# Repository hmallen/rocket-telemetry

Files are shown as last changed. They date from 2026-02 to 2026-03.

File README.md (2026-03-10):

# rocket-telemetry

High-rate flight data logger / telemetry firmware for a **Teensy 4.1** (Arduino framework via PlatformIO).

The firmware samples sensors, timestamps data with `micros()`, optionally anchors time to GNSS PPS, buffers records through a fast in-RAM ring (and optional PSRAM “spool”), and can write framed binary blocks to SD (Teensy 4.1 SDIO). A LoRa downlink module exists (enabled by default) and includes **FCC Part 97** guardrails.

## Status / defaults

`src/cfg.h` controls feature toggles. Current defaults in this repo:

- **SD logging**: enabled (`ENABLE_SD_LOGGER 1`)
- **PSRAM spool**: enabled (`ENABLE_PSRAM_SPOOL 1`)
- **GNSS**: enabled (`ENABLE_GNSS 1`) (raw UBX byte logging; configuration is a stub)
- **Sensors**: enabled (`ENABLE_SENSORS 1`)
- **LoRa**: enabled (`ENABLE_LORA 1`, `LORA_CONTROL_OPERATOR_OK 1`)

## Hardware

### Target MCU

- **Teensy 4.1**

### Sensors / peripherals (as implemented)

- **Barometer**: BMP3XX (configured via SPI) and BMP180 (I2C) as `baro2`
- **Gyro**: Adafruit L3GD20 (I2C)
- **Accelerometer**: Adafruit LSM303 (I2C)
- **GNSS**: two UARTs (`Serial1` primary, `Serial3` backup) + PPS input
- **SD**: Teensy 4.1 on-board SDIO (when enabled)
- **LoRa**: SX1276 via RadioLib (when enabled)

### Pin / bus configuration

All pins and bus settings are defined in `src/cfg.h`:

- **GNSS**
  - `GNSS_SERIAL_PRIMARY`: `Serial1`
  - `GNSS_SERIAL_BACKUP`: `Serial3`
  - `GNSS_PPS_PIN`: `2`
  - `GNSS_BAUD`: `115200`
- **Buzzer**: `BUZZER_PIN = 28` (short beep every ~2 seconds)
- **I2C**: `Wire`, `I2C_HZ = 400,000`
- **BMP3XX SPI**
  - `BMP_SPI_BUS = SPI`
  - `BMP_CS = 38`
- **LoRa (SX127x)**
  - `LORA_CS = 10`, `LORA_DIO0 = 9`, `LORA_RST = 8`

## Building / flashing

This is a PlatformIO project.

- **Environments**
  - `teensy41`
  - `teensy41_debug` (adds `-D DEBUG_MODE=1`)

Typical workflow (PlatformIO CLI):

```sh
pio run -e teensy41
pio run -e teensy41 -t upload
pio device monitor -b 115200
```

Serial monitor speed is `115200` (see `platformio.ini`).

## Runtime behavior (high level)

`src/main.cpp` drives the system:

- **Timebase**
  - `micros()` is the primary timestamp.
  - A PPS interrupt latches `t_us_at_pps`; a `REC_TIME_ANCHOR` record is emitted on each PPS edge.
- **GNSS**
  - Raw bytes from UART(s) are packed into `REC_GNSS_CHUNK` records.
  - Basic failover selects the “fresh” receiver based on a timeout (`GNSS_FAILOVER_TIMEOUT_US`).
  - Module configuration is currently a stub in `GnssUbx::configure()`.
- **Sensors**
  - Baro is sampled at `BARO_HZ`.
  - IMU sampling is scheduled at `IMU_HZ`.
- **Buffering**
  - Records are written into an internal `ByteRing` (DMA memory).
  - If enabled, the ring is drained into a PSRAM spool (`PsramSpool`) to absorb bursts.
- **SD block writing**
  - Data is drained into a `BlockBuilder` and written in 32 KiB blocks (when `ENABLE_SD_LOGGER` is enabled).

## Data format

### Record stream

Records are packed structs defined in `src/records.h`, each beginning with:

- `RecHdr { type, ver, len }`

Record types currently used:

- `REC_IMU_FAST` (accel/gyro)
- `REC_BARO`
- `REC_BARO2` (BMP180)
- `REC_GNSS_CHUNK` (raw bytes)
- `REC_TIME_ANCHOR` (PPS-to-GNSS time anchor)
- `REC_EVENT` (markers)
- `REC_STATS` (drop counters, voltages, SD write error counter)

### SD block framing

When SD logging is enabled, data is written as a sequence of blocks:

- `BlockHdr` (see `records.h`)
  - `magic`: `0x424D4C54` (`'TLMB'`)
  - `ver`: `1`
  - `seq`: monotonic block number
  - `t_start_us`: `micros()` at block start
  - `payload_len`: bytes following the header
  - `crc32`: CRC32 of payload
- `payload`: concatenated record bytes

Log files are named `LOG00000.BIN`, `LOG00001.BIN`, ... and are preallocated (see `PREALLOC_BYTES`).

## LoRa telemetry

The LoRa downlink code (`src/lora_link.*`) is intended for **FCC Part 97** amateur telemetry and includes multiple safeguards:

- Transmit is blocked unless you explicitly set `LORA_CONTROL_OPERATOR_OK 1`.
- Transmit is disabled at boot by default (`LORA_TX_ENABLE_AT_BOOT 0`).
- Telemetry payload uses a **custom binary format** and includes the callsign as an identifier byte sequence.

If you enable LoRa, you must also set a real `LORA_CALLSIGN` and ensure you are operating legally and under appropriate supervision.

## Tuning / configuration

Edit `src/cfg.h` for:

- Sample rates (`IMU_HZ`, `BARO_HZ`, `GNSS_HZ`, `LORA_HZ`)
- Buffer sizes (`RING_BYTES`, `SPOOL_BYTES`)
- SD write/sync parameters (`LOG_BLOCK_BYTES`, `SD_SYNC_MS`, `PREALLOC_BYTES`)
- Enabling/disabling features (the `ENABLE_*` macros)

## Receiver Tools

The project includes several ground-side companion tools located in the `receiver/` directory:

- **ESP32 Companion** (`receiver/esp32-companion`): An ESP32-based application using the Arduino framework and LVGL to display live telemetry data received over LoRa.
- **Pi Ground Station** (`receiver/pi`): A Python-based ground station server designed to run on a Raspberry Pi, providing a web interface, logging, and mapping capabilities.
- **Pico Emulator** (`receiver/pico`): A LoRa flight emulator for the Raspberry Pi Pico to generate simulated telemetry data for testing ground station setups.

## License

See `LICENSE`.

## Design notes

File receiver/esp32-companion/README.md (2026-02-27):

# ESP32 Companion Display (LVGL / CrowPanel 3.5)

This firmware targets the **CrowPanel 3.5" ESP32 HMI (480x320 landscape)** as a
ground-station telemetry display.

## What this now includes

- Full LVGL-based UI (rebuilt from scratch)
- UART-first companion transport to Pi ground station
- Optional Wi-Fi API/SSE transport fallback
- Optional Arduino OTA updates over Wi-Fi
- Optional SD-backed WAV playback for key flight events (armed-waiting, liftoff, apogee, drogue, main, landing)
- Telemetry dashboard:
  - Link status, RSSI, SNR, packet age
  - Flight phase, altitude AGL, vertical speed
  - Packet count, callsign
  - `TX_VBAT` (rocket telemetry battery)
  - `BAT_ADC` (local display board battery ADC)
- Collapsible action panel:
  - `BUZZER 1s`
  - `BUZZER 5s`
  - `SD START`
  - `SD STOP`
  - `TX ENABLE`
  - `TX DISABLE`
- Collapsible settings menu with touch calibration flow
- Touch calibration persistence in NVS (`Preferences`)

## Build + flash

```bash
pio run -e esp32dev
pio run -e esp32dev -t upload
pio device monitor -b 115200
```

OTA upload (after first USB flash and with OTA enabled in config):

```bash
pio run -e esp32dev-ota -t upload
```

## Configuration

1. Copy config template:

```bash
cp include/config.h.example include/config.h
```

2. Edit `include/config.h`:

- `COMPANION_LINK_UART` (`1` recommended for ground station)
- UART pins/baud for your board revision
- Wi-Fi + host settings if using API/SSE mode
- auth token if `/api/companion/cmd` is protected
- optional SD bootstrap (`COMPANION_SD_ENABLE`, `COMPANION_SD_CS_PIN`, `COMPANION_SD_SPI_FREQ`, `COMPANION_SD_SCK_PIN`, `COMPANION_SD_MISO_PIN`, `COMPANION_SD_MOSI_PIN`, `COMPANION_SD_SOUND_DIR`) for future sound assets
- optional event audio output (`COMPANION_AUDIO_ENABLE`, `COMPANION_AUDIO_SPK_PIN`, `COMPANION_AUDIO_PWM_*`) and per-event WAV file paths (`COMPANION_SOUND_FILE_*`)
- OTA settings (`OTA_ENABLE`, `OTA_HOSTNAME`, `OTA_PORT`, `OTA_PASSWORD`) if using OTA updates

When `OTA_ENABLE=1`, firmware keeps Wi-Fi active even in UART transport mode so OTA
updates remain available.

## Sound asset checklist (SD card)

Place WAV files under the SD sound directory (default: `/sounds`, configured by
`COMPANION_SD_SOUND_DIR`).

Primary event cues (via `COMPANION_SOUND_FILE_*` macros):

- `power_on.wav`
- `armed.wav`
- `calibrating.wav`
- `sensors_ready.wav`
- `waiting_for_location_fix.wav`
- `location_fix_acquired.wav`
- `launch_detect_mode.wav`
- `launch_detected.wav`
- `apogee.wav`
- `drogue_deployed.wav`
- `main_deployed.wav`
- `landing_detected.wav`
- `audio_test.wav` (used by **Play Test Sound**)

Spoken apogee altitude callout after landing requires numeric/unit clips:

- Number clips as `/sounds/<N>.wav` for:
  - 1..20
  - multiples of 10 below 100
  - multiples of 100 below 1000
  - multiples of 1000 up to 10000
- Unit clip: `meters.wav`

## CrowPanel pin notes

`platformio.ini` is configured for CrowPanel 3.5 with ILI9488 + XPT2046 defaults.

- Default profile uses: `TFT_MISO=12`, `TOUCH_CS=33`
- Elecrow v2.2 boards may require: `TFT_MISO=33`, `TOUCH_CS=12`

If your panel revision differs, override build flags in `platformio.ini`.

## Touch calibration

Use **Settings -> Calibrate Touch** from the LVGL action panel.

The calibration flow captures all four corners and stores bounds/swap config in
NVS so they persist across reboots.

## UART protocol

See `UART_PROTOCOL.md` for frame details and command IDs used between Pi and ESP32.

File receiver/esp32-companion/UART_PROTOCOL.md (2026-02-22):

# Companion UART Protocol (Pi Ground Station ↔ ESP32)

This defines the direct wired fallback/primary transport for the companion display
when the **ground station host is the Raspberry Pi**.

## Wiring

- Pi TX -> ESP32 RX (UART)
- Pi RX <- ESP32 TX (UART)
- GND -> GND
- 3.3V logic levels only on UART signal lines

Pi note:
- Use the Pi UART on GPIO14/15 (`/dev/serial0` preferred).
- Disable Linux serial console on that UART if needed, so your app has exclusive access.

ESP32 board note (LCDWiki E32R32P/E32N32P):
- The exposed UART header is tied to ESP32 UART0 (`RXD0=IO3`, `TXD0=IO1`) per LCDWiki docs.
- GPIO numbers are ESP32 GPIO IDs (not Raspberry Pi BCM numbering).

## Frame format

```text
SOF1  SOF2  VER  TYPE  SEQ(2)  LEN(2)  PAYLOAD(LEN)  CRC16(2)
0xA5  0x5A  0x01
```

CRC16 is CCITT over: `VER..PAYLOAD`.

## Message types

- `0x01` `MSG_TELEM_SNAPSHOT` (Pi -> ESP32)
- `0x02` `MSG_ALERT_EVENT` (Pi -> ESP32)
- `0x03` `MSG_HEARTBEAT` (both)
- `0x10` `MSG_CMD` (ESP32 -> Pi)
- `0x11` `MSG_CMD_ACK` (Pi -> ESP32)

## Transport selection

In `include/config.h`:

```cpp
#define COMPANION_LINK_UART 1
#define UART_BAUD 115200
#define UART_RX_PIN 3
#define UART_TX_PIN 1
```

On LCDWiki E32R32P/E32N32P, these map to UART0 (`RXD0=IO3`, `TXD0=IO1`) on the
exposed UART header.

Set `COMPANION_LINK_UART 0` to use Wi-Fi API/SSE instead.

## ESP32 implementation

- Parser/encoder: `src/serial/uart_proto.*`
- UART state bridge: `src/serial/uart_link.*`
- Controller auto-switches between UART and Wi-Fi using `COMPANION_LINK_UART`.

## Host-side implementation guidance (Pi)

Run a small UART bridge process on the Pi that:

1. Encodes telemetry into `MSG_TELEM_SNAPSHOT` frames at ~10 Hz
2. Parses incoming `MSG_CMD` from ESP32
3. Executes command actions in ground-station code (`buzzer`, `sd_start`, `sd_stop`)
4. Replies with `MSG_CMD_ACK`

This repository now treats UART companion mode as **Pi ground station ↔ ESP32**.

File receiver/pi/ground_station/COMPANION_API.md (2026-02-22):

# Companion Display API (ESP32 Touchscreen)

This API is intended for a Pi-companion touchscreen display (ESP32) and is separate from the browser UI API.

## Endpoints

### `GET /api/companion/state`
Returns a lightweight telemetry snapshot suitable for ESP32 rendering.

Response:

```json
{
  "state": {
    "ts": 1771290000.123,
    "seq": 123,
    "link": {
      "connected": true,
      "rssi": -91,
      "snr": 7.25,
      "crc_ok": true,
      "last_packet_age_ms": 84
    },
    "flight": {
      "phase": "coast",
      "packet_count": 2812,
      "callsign": "N0CALL"
    },
    "gps": { "lat_deg": 32.99, "lon_deg": -96.75, "alt_m": 512.3, "svs_used": 10, "svs_total": 18 },
    "alt": { "press_kpa": 98.7, "temp_c": 24.3 },
    "imu": { "ax_g": 0.02, "ay_g": -0.01, "az_g": 1.01, "gx_dps": 0.6, "gy_dps": -0.2, "gz_dps": 0.3 },
    "attitude": { "roll": 2.1, "pitch": -0.8, "yaw": 178.3, "filter": "madgwick" },
    "battery": { "vbat_v": 3.96, "bat_state_label": "OK" },
    "recovery": {
      "enabled": true,
      "phase": "coast",
      "altitude_agl_m": 402.1,
      "max_altitude_agl_m": 410.8,
      "vertical_speed_mps": 92.4,
      "drogue": { "deployed": false },
      "main": { "deployed": false }
    },
    "alerts": []
  }
}
```

### `GET /api/companion/events` (SSE)
SSE stream for live updates.

- `event: telemetry` for normal updates
- `event: hb` for heartbeat keepalive (1s cadence)

Example telemetry payload:

```json
{
  "event": "telemetry",
  "state": { "seq": 124, "link": { "rssi": -93 } }
}
```

### `POST /api/companion/cmd`
Sends a command through the same command path used by `/api/command`.

Auth required with either:
- `Authorization: Bearer <GS_AUTH_TOKEN>`
- `X-Auth-Token: <GS_AUTH_TOKEN>`

Request body examples:

```json
{"action": "sd_start"}
```

```json
{"action": "sd_stop"}
```

```json
{"action": "buzzer", "duration_s": 5}
```

## Notes

- The companion API is intentionally small and stable for microcontroller clients.
- `alerts` includes link staleness and low battery warnings for direct UI signaling.
- Link state is derived from telemetry timestamp freshness.

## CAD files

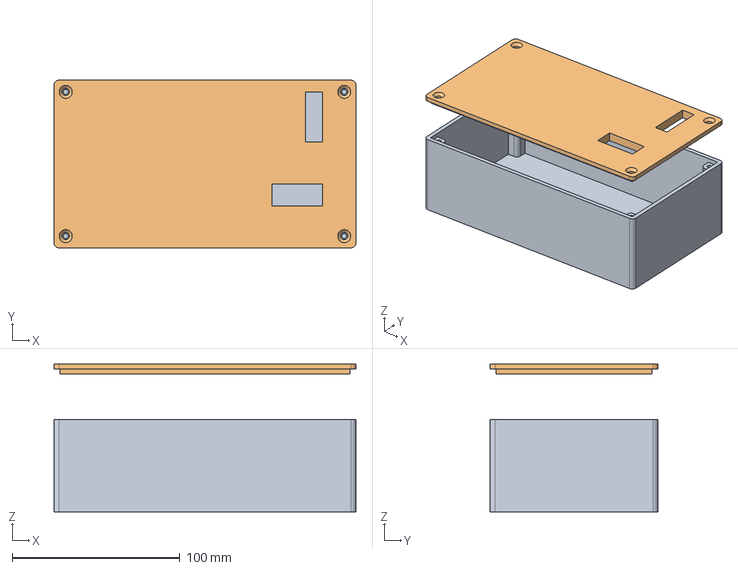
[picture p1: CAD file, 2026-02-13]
receiver/pi/enclosure/receiver_enclosure.FCStd
180.0 x 100.0 x 88.0 mm

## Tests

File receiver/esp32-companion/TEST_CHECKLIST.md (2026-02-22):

# ESP32 Companion Display Test Checklist

Use this checklist before field deployment.

## Bench Test (Required)

- [ ] Build firmware successfully (`pio run`)
- [ ] Flash device (`pio run -t upload`)
- [ ] Device boots with no crash loop (`pio device monitor`)
- [ ] Stale indicator appears after >3s without telemetry
- [ ] `BUZZ 1s` touch command works
- [ ] `BUZZ 5s` touch command works
- [ ] `SD TOGGLE` starts/stops logging as expected
- [ ] Command failures show error feedback on screen
- [ ] Touch calibration mode opens (top-left) and exits (top-right)
- [ ] Mapped touch coordinates align with button hitboxes

## Bench Test: Wi-Fi Mode (`COMPANION_LINK_UART=0`)

- [ ] Serial monitor shows Wi-Fi connect and no reconnect storm
- [ ] `GET /api/companion/state` returns valid JSON from Pi
- [ ] SSE stream connects (`/api/companion/events`) and updates continuously
- [ ] Link status changes correctly when Pi service is stopped/restarted

## Bench Test: UART Mode (`COMPANION_LINK_UART=1`)

- [ ] Wiring verified: Pi TX -> ESP32 RX, Pi RX <- ESP32 TX, GND common
- [ ] Logic level verified: UART signals are 3.3V (no 5V on RX/TX)
- [ ] UART config matches both sides (baud + pins)
- [ ] ESP32 receives telemetry over UART and updates phase/altitude/packet count
- [ ] Pulling one UART wire causes stale/link-down indication within ~3s
- [ ] Reconnecting UART recovers without reboot
- [ ] UART command path works end-to-end (BUZZ/SD toggle + ACK feedback)
- [ ] No framing instability under load (no persistent garbage/lock-up)

## Security & Network

- [ ] `GS_AUTH_TOKEN` is set on ESP32 when command auth is enabled on Pi
- [ ] `/api/companion/cmd` returns 401 without token (when auth enabled)
- [ ] Pi bind/access mode matches expected launch network policy

## UART Robustness (Recommended)

- [ ] 30+ minute run with continuous UART telemetry has no parser lockup
- [ ] Power cycle ESP32 while Pi ground station runs: link recovers automatically
- [ ] Restart/power cycle Pi ground station while ESP32 runs: stale alarm then recovery
- [ ] Cable wiggle test does not trigger false commands
- [ ] Command retry/timeout behavior is acceptable for field use

## Field Simulation (Recommended)

- [ ] Ground station runs for 30+ minutes without UI freeze
- [ ] Reconnect behavior works after Wi-Fi disruption/rejoin
- [ ] Alert strip shows phase transitions and link events
- [ ] Display remains readable in expected daylight conditions
- [ ] No accidental command triggers from noisy touch events

## Pre-Launch

- [ ] Confirm final touch calibration constants in `include/config.h`
- [ ] Confirm selected transport mode (`COMPANION_LINK_UART` 0 or 1)
- [ ] If Wi-Fi mode: confirm correct ground station host/IP and port
- [ ] If UART mode: confirm final UART pins/baud and cable strain relief
- [ ] Confirm buzzer + SD command behavior with live radio link
- [ ] Keep fallback control path available (laptop/web UI)

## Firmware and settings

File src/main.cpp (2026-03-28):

#include <Arduino.h>

#include "cfg.h"
#include "records.h"
#include "byte_ring.h"
#include "psram_spool.h"
#include "block_builder.h"
#include "crc32.h"
#include "sd_logger.h"
#include "timebase.h"
#include "gnss_ubx.h"
#include "sensors.h"
#include "lora_link.h"

// Internal fast ring
DMAMEM static uint8_t ring_mem[RING_BYTES];
static ByteRing ring;

// PSRAM spool
#if ENABLE_PSRAM_SPOOL
EXTMEM static uint8_t spool_mem[SPOOL_BYTES];
static PsramSpool spool;
#endif

static BlockBuilder block;
static SdLogger sdlog;
static uint32_t block_seq = 0;
static bool sd_logging_enabled = false;
constexpr uint32_t SD_ROTATE_DRAIN_MAX_MS = 3000;

static inline bool build_and_write_block_from_source(uint32_t now_ms, bool force_write = false);
static inline void pump_ring_to_spool();
static void sd_logging_flush_pending(uint32_t now_ms, uint32_t max_drain_ms);
static inline void ring_write_sd_log_open_event(int16_t reason);
static inline void ring_write_sd_log_close_event(int16_t reason);

#if ENABLE_SD_DUMP
static const char* sd_dump_record_name(uint8_t type) {
  switch (type) {
    case REC_IMU_FAST: return "REC_IMU_FAST";
    case REC_BARO: return "REC_BARO";
    case REC_GNSS_CHUNK: return "REC_GNSS_CHUNK";
    case REC_TIME_ANCHOR: return "REC_TIME_ANCHOR";
    case REC_EVENT: return "REC_EVENT";
    case REC_STATS: return "REC_STATS";
    case REC_BARO2: return "REC_BARO2";
    default: return "REC_UNKNOWN";
  }
}

static void sd_dump_print_ascii(const uint8_t* data, uint16_t n, uint16_t preview) {
  Serial.print("    ascii: ");
  for (uint16_t i = 0; i < preview; ++i) {
    char c = (data[i] >= 32 && data[i] <= 126) ? (char)data[i] : '.';
    Serial.write(c);
  }
  if (n > preview) {
    Serial.print(" ...");
  }
  Serial.println();
}

static void sd_dump_print_hex(const uint8_t* data, uint16_t n, uint16_t preview) {
  Serial.print("    hex:   ");
  for (uint16_t i = 0; i < preview; ++i) {
    if (i && (i % 16 == 0)) {
      Serial.print("\n          ");
    }
    if (data[i] < 0x10) Serial.print('0');
    Serial.print(data[i], HEX);
    Serial.print(' ');
  }
  if (n > preview) {
    Serial.print("... (");
    Serial.print(n);
    Serial.println(" bytes)");
  } else {
    Serial.println();
  }
}

static void sd_dump_print_record(uint32_t idx,
                                 uint8_t type,
                                 uint8_t ver,
                                 uint16_t len,
                                 const uint8_t* payload,
                                 uint16_t payload_len) {
  const char* name = sd_dump_record_name(type);
  Serial.printf("  [%lu] %s ver=%u len=%u\n",
                (unsigned long)idx, name, (unsigned)ver, (unsigned)len);
  const uint16_t preview = min(payload_len, (uint16_t)64);

  if (type == REC_IMU_FAST && payload_len >= (sizeof(RecImuFast) - sizeof(RecHdr))) {
    RecImuFast r{};
    memcpy(&r.t_us, payload, sizeof(RecImuFast) - sizeof(RecHdr));
    Serial.printf("    t_us=%lu ax=%d ay=%d az=%d gx=%d gy=%d gz=%d temp=%d status=0x%04x\n",
                  (unsigned long)r.t_us, (int)r.ax, (int)r.ay, (int)r.az,
                  (int)r.gx, (int)r.gy, (int)r.gz, (int)r.temp, (unsigned)r.status);
    return;
  }
  if ((type == REC_BARO || type == REC_BARO2) && payload_len >= (sizeof(RecBaro) - sizeof(RecHdr))) {
    RecBaro r{};
    memcpy(&r.t_us, payload, sizeof(RecBaro) - sizeof(RecHdr));
    Serial.printf("    t_us=%lu press_pa_x10=%ld temp_c_x100=%d status=0x%04x\n",
                  (unsigned long)r.t_us, (long)r.press_pa_x10, (int)r.temp_c_x100,
                  (unsigned)r.status);
    return;
  }
  if (type == REC_GNSS_CHUNK && payload_len >= 6) {
    uint32_t t_us = 0;
    uint16_t n = 0;
    memcpy(&t_us, payload, sizeof(t_us));
    memcpy(&n, payload + sizeof(t_us), sizeof(n));
    uint16_t avail = payload_len > 6 ? (payload_len - 6) : 0;
    uint16_t n_use = min(n, avail);
    Serial.printf("    t_us=%lu n=%u\n", (unsigned long)t_us, (unsigned)n);
    if (n_use) {
      const uint8_t* data = payload + 6;
      sd_dump_print_ascii(data, n_use, min(n_use, preview));
      sd_dump_print_hex(data, n_use, min(n_use, preview));
    }
    return;
  }
  if (type == REC_TIME_ANCHOR && payload_len >= (sizeof(RecTimeAnchor) - sizeof(RecHdr))) {
    RecTimeAnchor r{};
    memcpy(&r.t_us_at_pps, payload, sizeof(RecTimeAnchor) - sizeof(RecHdr));
    Serial.printf("    t_us_at_pps=%lu gps_week=%u tow_ms=%lu fix_ok=%u\n",
                  (unsigned long)r.t_us_at_pps, (unsigned)r.gps_week,
                  (unsigned long)r.tow_ms, (unsigned)r.fix_ok);
    return;
  }
  if (type == REC_EVENT && payload_len >= (sizeof(RecEvent) - sizeof(RecHdr))) {
    RecEvent r{};
    memcpy(&r.t_us, payload, sizeof(RecEvent) - sizeof(RecHdr));
    if (record_event_is_lora_cmd_rx(r.event_id)) {
      const uint8_t cmd = record_event_lora_cmd_rx_cmd(r.event_id);
      const char* cmd_name = record_lora_cmd_name(cmd);
      Serial.printf("    t_us=%lu event=gs_cmd_rx cmd=0x%02X (%s) arg=%d\n",
                    (unsigned long)r.t_us,
                    (unsigned)cmd,
                    cmd_name != nullptr ? cmd_name : "unknown",
                    (int)r.value);
    } else if (record_event_is_sd_log_open(r.event_id)) {
      const char* reason = record_sd_log_open_reason_name(r.value);
      Serial.printf("    t_us=%lu event=sd_log_open reason=%s(%d)\n",
                    (unsigned long)r.t_us,
                    reason != nullptr ? reason : "unknown",
                    (int)r.value);
    } else if (record_event_is_sd_log_close(r.event_id)) {
      const char* reason = record_sd_log_close_reason_name(r.value);
      Serial.printf("    t_us=%lu event=sd_log_close reason=%s(%d)\n",
                    (unsigned long)r.t_us,
                    reason != nullptr ? reason : "unknown",
                    (int)r.value);
    } else {
      Serial.printf("    t_us=%lu event_id=%u value=%d\n",
                    (unsigned long)r.t_us, (unsigned)r.event_id, (int)r.value);
    }
    return;
  }
  if (type == REC_STATS && payload_len >= (sizeof(RecStats) - sizeof(RecHdr))) {
    RecStats r{};
    memcpy(&r.t_us, payload, sizeof(RecStats) - sizeof(RecHdr));
    Serial.printf("    t_us=%lu ring_drops=%lu spool_drops=%lu sd_write_errs=%lu vbat_mv=%u bat_state=%u\n",
                  (unsigned long)r.t_us, (unsigned long)r.ring_drops,
                  (unsigned long)r.spool_drops, (unsigned long)r.sd_write_errs,
                  (unsigned)r.vbat_mv, (unsigned)r.bat_state);
    return;
  }

  if (payload_len) {
    sd_dump_print_hex(payload, payload_len, preview);
  }
}

static bool sd_dump_skip_bytes(FsFile& file, uint32_t n, uint32_t* crc) {
  uint8_t scratch[64];
  while (n) {
    uint32_t chunk = min(n, (uint32_t)sizeof(scratch));
    int32_t r = file.read(scratch, chunk);
    if (r <= 0) return false;
    if (crc) {
      *crc = crc32_update(*crc, scratch, (size_t)r);
    }
    n -= (uint32_t)r;
  }
  return true;
}

static void sd_dump_log() {
  Serial.println("\nsd: dump requested");
#if !ENABLE_SD_LOGGER
  Serial.println("sd: logging disabled");
  return;
#endif
  sdlog.force_sync();
  const char* log_name = sdlog.log_name();
  if (!log_name) {
    Serial.println("sd: no log file name");
    return;
  }

  FsFile file = sdlog.open_log_read();
  if (!file) {
    Serial.println("sd: open log for read failed");
    return;
  }

  if (!file.seekSet(0)) {
    Serial.println("sd: seek failed");
    file.close();
    return;
  }

  Serial.print("sd: dumping ");
  Serial.println(log_name);

  uint32_t block_idx = 0;
  while (true) {
    BlockHdr hdr{};
    int32_t r = file.read((uint8_t*)&hdr, sizeof(hdr));
    if (r == 0) break;
    if (r < (int32_t)sizeof(hdr)) {
      Serial.println("sd: truncated block header");
      break;
    }
    if (hdr.hdr_len < sizeof(hdr)) {
      Serial.println("sd: invalid block header length");
      break;
    }
    if (hdr.hdr_len > sizeof(hdr)) {
      if (!sd_dump_skip_bytes(file, hdr.hdr_len - sizeof(hdr), nullptr)) {
        Serial.println("sd: truncated block header padding");
        break;
      }
    }

    if (hdr.magic != BLOCK_MAGIC) {
      if (hdr.magic == 0) {
        Serial.println("sd: reached preallocated empty region");
      } else {
        Serial.printf("sd: invalid block magic 0x%08lx\n", (unsigned long)hdr.magic);
      }
      break;
    }

    Serial.printf("BLOCK seq=%lu t_start_us=%lu payload_len=%lu\n",
                  (unsigned long)hdr.seq,
                  (unsigned long)hdr.t_start_us,
                  (unsigned long)hdr.payload_len);

    uint32_t remaining = hdr.payload_len;
    uint32_t crc = 0u;
    uint32_t rec_idx = 0;

    while (remaining >= sizeof(RecHdr)) {
      uint8_t rec_hdr[sizeof(RecHdr)];
      int32_t rh = file.read(rec_hdr, sizeof(rec_hdr));
      if (rh < (int32_t)sizeof(rec_hdr)) {
        Serial.println("sd: truncated record header");
        remaining = 0;
        break;
      }
      remaining -= sizeof(rec_hdr);
      crc = crc32_update(crc, rec_hdr, sizeof(rec_hdr));

      const uint8_t rec_type = rec_hdr[0];
      const uint8_t rec_ver = rec_hdr[1];
      const uint16_t rec_len = (uint16_t)rec_hdr[2] | ((uint16_t)rec_hdr[3] << 8);
      if (rec_len < sizeof(RecHdr) || rec_len - sizeof(RecHdr) > remaining) {
        Serial.println("sd: invalid record length");
        if (!sd_dump_skip_bytes(file, remaining, &crc)) {
          remaining = 0;
        }
        break;
      }

      const uint16_t payload_len = rec_len - sizeof(RecHdr);
      uint8_t rec_buf[GNSS_CHUNK_MAX + 16];
      uint16_t to_read = payload_len;
      if (to_read > sizeof(rec_buf)) {
        to_read = sizeof(rec_buf);
      }
      if (to_read) {
        int32_t rp = file.read(rec_buf, to_read);
        if (rp < (int32_t)to_read) {
          Serial.println("sd: truncated record payload");
          remaining = 0;
          break;
        }
        crc = crc32_update(crc, rec_buf, to_read);
      }

      if (payload_len > to_read) {
        uint32_t leftover = payload_len - to_read;
        if (!sd_dump_skip_bytes(file, leftover, &crc)) {
          Serial.println("sd: truncated record payload");
          remaining = 0;
          break;
        }
      }

      remaining -= payload_len;
      sd_dump_print_record(rec_idx, rec_type, rec_ver, rec_len, rec_buf, min(payload_len, to_read));
      rec_idx++;
    }

    if (remaining) {
      sd_dump_skip_bytes(file, remaining, &crc);
    }

    const bool crc_ok = (crc == hdr.crc32);
    Serial.printf("BLOCK CRC32 %s (0x%08lx)\n", crc_ok ? "OK" : "BAD", (unsigned long)crc);
    block_idx++;
  }

  file.close();
  Serial.println("sd: dump complete");
}

static void sd_clear_logs() {
  Serial.println("\nsd: clear requested");
#if !ENABLE_SD_LOGGER
  Serial.println("sd: logging disabled");
  return;
#endif
  const bool restart_logging = sd_logging_enabled;
  if (sd_logging_enabled) {
    ring_write_sd_log_close_event(REC_EVENT_VALUE_SD_LOG_CLOSE_CLEAR);
    sd_logging_flush_pending(millis(), SD_ROTATE_DRAIN_MAX_MS);
    sdlog.force_sync();
    if (!sdlog.close_log()) {
      Serial.println("sd: close failed before clear");
    }
    sd_logging_enabled = false;
  }
  if (!sdlog.clear_logs()) {
    Serial.println("sd: clear failed");
    return;
  }

  block_seq = 0;
  block.reset(block_seq, micros());
  ring.init(ring_mem, RING_BYTES);
#if ENABLE_PSRAM_SPOOL
  spool.init(spool_mem, SPOOL_BYTES);
#endif
  sd_logging_enabled = false;

  if (restart_logging) {
    if (!sdlog.open_new_log(PREALLOC_BYTES)) {
      Serial.println("sd: open new log failed");
      return;
    }

    sd_logging_enabled = true;
    ring_write_sd_log_open_event(REC_EVENT_VALUE_SD_LOG_OPEN_RESTART);
    sd_logging_flush_pending(millis(), SD_ROTATE_DRAIN_MAX_MS);
    const char* log_name = sdlog.log_name();
    if (log_name) {
      Serial.print("sd: new log ");
      Serial.println(log_name);
    } else {
      Serial.println("sd: new log started");
    }
  }
}

static void sd_rotate_log() {
  Serial.println("\nsd: rotate requested");
#if !ENABLE_SD_LOGGER
  Serial.println("sd: logging disabled");
  return;
#endif
  char old_name[32];
  old_name[0] = '\0';
  const char* log_name = sdlog.log_name();
  if (log_name) {
    snprintf(old_name, sizeof(old_name), "%s", log_name);
  }

  ring_write_sd_log_close_event(REC_EVENT_VALUE_SD_LOG_CLOSE_ROTATE);
  sd_logging_flush_pending(millis(), SD_ROTATE_DRAIN_MAX_MS);

  if (!sdlog.close_log()) {
    Serial.println("sd: close failed");
  }
  if (!sdlog.open_new_log(PREALLOC_BYTES)) {
    Serial.println("sd: open new log failed");
    sd_logging_enabled = false;
    return;
  }

  sd_logging_enabled = true;
  ring_write_sd_log_open_event(REC_EVENT_VALUE_SD_LOG_OPEN_ROTATE);
  sd_logging_flush_pending(millis(), SD_ROTATE_DRAIN_MAX_MS);
  if (old_name[0]) {
    Serial.print("sd: closed ");
    Serial.println(old_name);
  }
  log_name = sdlog.log_name();
  if (log_name) {
    Serial.print("sd: new log ");
    Serial.println(log_name);
  }
}

static void sd_dump_print_help() {
  Serial.println("sd dump commands:");
  Serial.println("  c: clear SD logs (keeps logging off unless already on)");
  Serial.println("  d: dump SD log to serial");
  Serial.println("  n: close current log + start new log");
  Serial.println("  h/? : help");
}
#endif
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
void loop() {
  static uint32_t last_imu_us  = 0;
  static uint32_t last_baro_us = 0;
  static uint32_t last_baro2_us = 0;
  static int32_t last_press_pa_x10 = 0;
  static int16_t last_temp_c_x100 = 0;
  static uint32_t last_stats_ms = 0;
  static bool primary_3d_beeped = false;
  static ImuSample last_imu_sample{};
  static bool have_imu_sample = false;

  static float vbat_filt_v = 0.0f;
  static uint32_t vbat_last_sample_ms = 0;
  static uint32_t shed_below_start_ms = 0;
  static uint32_t cutoff_below_start_ms = 0;

#if DEBUG_MODE
  static uint32_t last_dbg_ms = 0;
  static ImuSample last_imu{};
  static uint32_t last_imu_dbg_us = 0;
#endif

  const uint32_t now_us = micros();
  const uint32_t now_ms = millis();

#if ENABLE_SD_DUMP
  while (Serial.available()) {
    const int c = Serial.read();
    if (c < 0) break;
    if (c == 'c' || c == 'C') {
      sd_clear_logs();
    } else if (c == 'd' || c == 'D') {
      sd_dump_log();
    } else if (c == 'n' || c == 'N') {
      sd_rotate_log();
    } else if (c == 'h' || c == '?') {
      sd_dump_print_help();
    }
  }
#endif

  if (vbat_last_sample_ms == 0 || (uint32_t)(now_ms - vbat_last_sample_ms) >= 50) {
    vbat_last_sample_ms = now_ms;

    uint32_t sum = 0;
    for (uint8_t i = 0; i < VBAT_AVG_SAMPLES; ++i) {
      sum += (uint32_t)analogRead(VBAT_PIN);
    }
    const float counts = (float)sum / (float)VBAT_AVG_SAMPLES;
    const float vadc = counts * (3.3f / 4095.0f);
    const float vbat = vadc * VBAT_DIVIDER_SCALE * VBAT_CAL_SCALE;

    if (vbat_filt_v == 0.0f) vbat_filt_v = vbat;
    else vbat_filt_v = vbat_filt_v + VBAT_LP_ALPHA * (vbat - vbat_filt_v);

    const float vf = vbat_filt_v;

    if (g_bat_state == BAT_OK) {
      if (vf <= VBAT_WARN_V) g_bat_state = BAT_WARN;
    } else if (g_bat_state == BAT_WARN) {
      if (vf <= VBAT_SHED_V) {
        if (shed_below_start_ms == 0) shed_below_start_ms = now_ms;
        if ((uint32_t)(now_ms - shed_below_start_ms) >= VBAT_DWELL_MS) {
          g_bat_state = BAT_SHED;
          shed_below_start_ms = 0;
        }
      } else {
        shed_below_start_ms = 0;
      }
      if (vf >= (VBAT_WARN_V + VBAT_HYST_V)) g_bat_state = BAT_OK;
    } else if (g_bat_state == BAT_SHED) {
      if (vf <= VBAT_CUTOFF_V) {
        if (cutoff_below_start_ms == 0) cutoff_below_start_ms = now_ms;
        if ((uint32_t)(now_ms - cutoff_below_start_ms) >= VBAT_DWELL_MS) {
          g_bat_state = BAT_CUTOFF;
          cutoff_below_start_ms = 0;
        }
      } else {
        cutoff_below_start_ms = 0;
      }
      if (vf >= (VBAT_SHED_V + VBAT_HYST_V)) g_bat_state = BAT_WARN;
    } else {
      if (vf >= (VBAT_CUTOFF_V + VBAT_HYST_V)) g_bat_state = BAT_SHED;
    }

    if (SENSOR_RAIL_EN_PIN != 255) {
      const bool rail_on = (g_bat_state == BAT_OK) || (g_bat_state == BAT_WARN);
      digitalWrite(SENSOR_RAIL_EN_PIN, rail_on ? HIGH : LOW);
    }

    g_vbat_mv = (uint16_t)max(0, (int)lrintf(vf * 1000.0f));
  }

  buzzer_poll(now_ms);

#if DEBUG_MODE
  if ((uint32_t)(now_ms - last_dbg_ms) >= 1000) {
    last_dbg_ms = now_ms;
    DBG_PRINTF("t=%lu ms baro_pa=%.1f temp_c=%.2f vbat=%.3f bat_state=%u ring_avail=%lu ring_drops=%lu",
               (unsigned long)now_ms,
               (double)last_press_pa_x10 / 10.0,
               (double)last_temp_c_x100 / 100.0,
               (double)g_vbat_mv / 1000.0,
               (unsigned)g_bat_state,
               (unsigned long)ring.available(), (unsigned long)ring.drops());
    if (last_imu_dbg_us != 0) {
      DBG_PRINTF(" imu_ax=%d ay=%d az=%d gx=%d gy=%d gz=%d ist=0x%04x",
                 (int)last_imu.ax, (int)last_imu.ay, (int)last_imu.az,
                 (int)last_imu.gx, (int)last_imu.gy, (int)last_imu.gz,
                 (unsigned)last_imu.status);
    } else {
      DBG_PRINT(" imu=none");
    }
#if ENABLE_PSRAM_SPOOL
    DBG_PRINTF(" spool_avail=%lu spool_drops=%lu", (unsigned long)spool.available(),
               (unsigned long)spool.drops());
#endif
#if ENABLE_GNSS
    const bool primary_fresh_dbg = gnss_primary.fresh(now_us, GNSS_FAILOVER_TIMEOUT_US);
    const bool backup_fresh_dbg  = gnss_backup.fresh(now_us, GNSS_FAILOVER_TIMEOUT_US);
    const bool primary_parsed_dbg = gnss_primary.parsed_fresh(now_us, GNSS_FAILOVER_TIMEOUT_US);
    const bool backup_parsed_dbg  = gnss_backup.parsed_fresh(now_us, GNSS_FAILOVER_TIMEOUT_US);
    const GnssTime& pt = gnss_primary.time();
    const GnssTime& bt = gnss_backup.time();

    DBG_PRINTF(" gnss_sel=%c", gnss_use_backup_as_primary ? 'B' : 'P');
    DBG_PRINTF(" gnss_p_fresh=%u parsed=%u fix_ok=%u fix=%u lat=%.7f lon=%.7f alt_m=%.3f tow_ms=%lu week=%u bytes=%lu",
               (unsigned)primary_fresh_dbg,
               (unsigned)primary_parsed_dbg,
               (unsigned)pt.fix_ok, (unsigned)pt.fix_type,
               (double)pt.lat_e7 / 1e7,
               (double)pt.lon_e7 / 1e7,
               (double)pt.height_mm / 1000.0,
               (unsigned long)pt.tow_ms, (unsigned)pt.week,
               (unsigned long)gnss_primary.bytes_rx());

    DBG_PRINTF(" gnss_b_fresh=%u parsed=%u fix_ok=%u fix=%u lat=%.7f lon=%.7f alt_m=%.3f tow_ms=%lu week=%u bytes=%lu",
               (unsigned)backup_fresh_dbg,
               (unsigned)backup_parsed_dbg,
               (unsigned)bt.fix_ok, (unsigned)bt.fix_type,
               (double)bt.lat_e7 / 1e7,
               (double)bt.lon_e7 / 1e7,
               (double)bt.height_mm / 1000.0,
               (unsigned long)bt.tow_ms, (unsigned)bt.week,
               (unsigned long)gnss_backup.bytes_rx());

    const GnssTime& gt = gnss_use_backup_as_primary ? bt : pt;
    if (gt.last_sat_ms != 0 || gt.navsat_num_svs_total != 0 || gt.navsat_num_svs != 0) {
      DBG_PRINTF(" sat=%u/%u used=%u",
                 (unsigned)gt.navsat_n,
                 (unsigned)gt.navsat_num_svs_total,
                 (unsigned)gt.navsat_num_svs);
      const uint8_t show = (gt.navsat_n < 4) ? gt.navsat_n : 4;
      for (uint8_t i = 0; i < show; ++i) {
        const auto& s = gt.navsat[i];
        DBG_PRINTF(" [%u:%u cno=%u el=%d]", (unsigned)s.gnss_id, (unsigned)s.sv_id,
                   (unsigned)s.cno, (int)s.elev_deg);
      }
    } else {
      DBG_PRINT(" sat=none");
    }
#endif
    DBG_PRINTF(" sd_errs=%lu\n", (unsigned long)sdlog.write_errs());
  }
#endif

  // PPS anchor
  uint32_t t_pps;
  if (time_pop_pps(t_pps)) {
#if ENABLE_GNSS
    const bool primary_anchor_fresh = gnss_primary.parsed_fresh(now_us, GNSS_FAILOVER_TIMEOUT_US);
    const bool backup_anchor_fresh = gnss_backup.parsed_fresh(now_us, GNSS_FAILOVER_TIMEOUT_US);
    const GnssUbx& anchor = primary_anchor_fresh
                              ? gnss_primary
                              : (backup_anchor_fresh
                                   ? gnss_backup
                                   : (gnss_primary.fresh(now_us, GNSS_FAILOVER_TIMEOUT_US)
                                        ? gnss_primary
                                        : gnss_backup));
    ring_write_time_anchor(t_pps, anchor.time());
#else
    GnssTime dummy{};
    ring_write_time_anchor(t_pps, dummy);
#endif
  }

#if ENABLE_GNSS
  if (!primary_3d_beeped) {
    const GnssTime& pt = gnss_primary.time();
    const bool primary_solution_fresh = gnss_primary.parsed_fresh(now_us, GNSS_FAILOVER_TIMEOUT_US);
    const bool primary_3d = primary_solution_fresh && pt.fix_ok && pt.fix_type >= 3;
    if (primary_3d && !buzzer_busy()) {
      buzzer_start_seq(150, 150, 2, now_ms);
      primary_3d_beeped = true;
    }
  }

  const bool primary_solution_fresh = gnss_primary.parsed_fresh(now_us, GNSS_FAILOVER_TIMEOUT_US);
  const bool backup_solution_fresh  = gnss_backup.parsed_fresh(now_us, GNSS_FAILOVER_TIMEOUT_US);

  if (!gnss_use_backup_as_primary) {
    if (!primary_solution_fresh && backup_solution_fresh) gnss_use_backup_as_primary = true;
  } else {
    if (primary_solution_fresh) gnss_use_backup_as_primary = false;
  }

  ByteRing* ring_out_primary = gnss_use_backup_as_primary ? nullptr : &ring;
  ByteRing* ring_out_backup  = gnss_use_backup_as_primary ? &ring : nullptr;

  if (!sd_logging_enabled) {
    ring_out_primary = nullptr;
    ring_out_backup = nullptr;
  }

  gnss_primary.poll(ring_out_primary, now_us);
  gnss_backup.poll(ring_out_backup, now_us);
#endif
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

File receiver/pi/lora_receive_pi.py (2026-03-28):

import os
import subprocess
import sys
import threading
import time
from dataclasses import dataclass

try:
    import spidev
    import RPi.GPIO as GPIO
except ImportError as e:
    raise SystemExit(
        "Missing Raspberry Pi dependencies. Install with:\n"
        "  sudo apt-get install -y python3-spidev python3-rpi.gpio\n"
        "and enable SPI (raspi-config) if needed."
    ) from e

try:
    from smbus2 import SMBus
except ImportError:
    SMBus = None


if not hasattr(time, "sleep_ms"):
    def sleep_ms(ms):
        time.sleep(ms / 1000.0)
    time.sleep_ms = sleep_ms


def _env_str(name, default):
    value = os.environ.get(name)
    if value is None:
        return default
    value = str(value).strip()
    return value if value else default


def _env_int(name, default):
    try:
        return int(_env_str(name, default))
    except (TypeError, ValueError):
        return int(default)


def _env_float(name, default):
    try:
        return float(_env_str(name, default))
    except (TypeError, ValueError):
        return float(default)


def _env_bool(name, default=False):
    value = os.environ.get(name)
    if value is None:
        return default
    return str(value).strip().lower() in ("1", "true", "yes", "on")


@dataclass(frozen=True)
class VoltageMonitorConfig:
    i2c_bus: int = 1
    # PiZ-UpTime 2.0 ADC address.
    address: int = 0x49

    ch_vin: int = 0b11000001
    # PiZ-UpTime sample mapping: channel 1 = output, channel 2 = battery.
    ch_vout: int = 0b11010001
    ch_vbatt: int = 0b11100001
    ch_tempv: int = 0b11110001

    # ADS word decode mode: "swapped" (legacy SMBus byte-swapped),
    # "native" (no byte swap), or "auto" (heuristic selection).
    adc_decode_mode: str = "auto"
    ground_batt_adc_decode_mode: str = "auto"

    vref: float = 6.144
    max_reading: float = 2047.0

    group_sleep_s: float = 2.0
    channel_sleep_s: float = _env_float("GS_UPS_CHANNEL_SLEEP_S", 0.10)

    vbatt_min: float = _env_float("GS_UPS_VBATT_MIN_V", 3.1)
    vin_min: float = _env_float("GS_UPS_VIN_MIN_V", 3.8)
    temp_min_c: float = 5.0
    temp_max_c: float = 60.0

    shutdown_cmd: str = _env_str("GS_VOLTAGE_MONITOR_SHUTDOWN_CMD", "sudo shutdown -h now")
    temp_profile: str = "piz_uptime_2"

    # External ADS1115 for ground battery sensing (A0 via 100k/100k divider).
    ground_batt_address: int = 0x48
    ground_batt_channel: int = 0b11000001
    ground_batt_divider_scale: float = 2.0
    ground_batt_cal_scale: float = 1.0
    ground_batt_min_v: float = 0.2
    ground_batt_warn_v: float = _env_float("GS_GROUND_BATT_WARN_V", 6.8)
    ground_batt_shutdown_v: float = _env_float("GS_GROUND_BATT_SHUTDOWN_V", 6.4)
    ground_batt_shutdown_samples: int = max(1, _env_int("GS_GROUND_BATT_SHUTDOWN_SAMPLES", 3))
    ground_batt_auto_shutdown: bool = _env_bool("GS_GROUND_BATT_AUTO_SHUTDOWN", True)


VOLTAGE_MONITOR_CFG = VoltageMonitorConfig()

_VOLTAGE_STATE_LOCK = threading.Lock()
_VOLTAGE_STATE = {
    "timestamp": None,
    "enabled": False,
    "running": False,
    "status": "init",
    "disabled_reason": None,
    "vin_v": None,
    "vout_v": None,
    "vbatt_v": None,
    "ground_vbat_v": None,
    "temp_v": None,
    "temp_c": None,
    "temp_f": None,
    "warning": None,
    "shutdown_triggered": False,
    "shutdown_reason": None,
    "last_error": None,
    "ups_vin_min_v": VOLTAGE_MONITOR_CFG.vin_min,
    "ups_vbatt_min_v": VOLTAGE_MONITOR_CFG.vbatt_min,
    "ground_batt_warn_v": VOLTAGE_MONITOR_CFG.ground_batt_warn_v,
    "ground_batt_shutdown_v": VOLTAGE_MONITOR_CFG.ground_batt_shutdown_v,
    "ground_batt_shutdown_samples": VOLTAGE_MONITOR_CFG.ground_batt_shutdown_samples,
    "ground_batt_auto_shutdown": VOLTAGE_MONITOR_CFG.ground_batt_auto_shutdown,
    "ground_batt_low_samples": 0,
    "adc_decode_mode": VOLTAGE_MONITOR_CFG.adc_decode_mode,
    "ground_batt_adc_decode_mode": VOLTAGE_MONITOR_CFG.ground_batt_adc_decode_mode,
}


def _update_voltage_state(**changes):
    with _VOLTAGE_STATE_LOCK:
        _VOLTAGE_STATE.update(changes)


def get_voltage_monitor_snapshot():
    with _VOLTAGE_STATE_LOCK:
        return dict(_VOLTAGE_STATE)


def _decode_adc_voltage_from_raw(raw, cfg, decode_mode):
    raw_i = int(raw) & 0xFFFF

    swapped_word = (((raw_i & 0xFF) << 8) | ((raw_i >> 8) & 0xFF))
    swapped_value = (swapped_word >> 4) & 0x0FFF
    swapped_v = (swapped_value / cfg.max_reading) * cfg.vref

    native_value = (raw_i >> 4) & 0x0FFF
    native_v = (native_value / cfg.max_reading) * cfg.vref

    mode = str(decode_mode or "swapped").strip().lower()
    if mode in ("native", "no_swap", "noswap", "direct"):
        return native_v
    if mode in ("swapped", "swap"):
        return swapped_v

    # Auto mode: pick whichever decode path avoids implausibly tiny values
    # while preserving backward compatibility when both look plausible.
    if native_v >= 2.0 and swapped_v < 1.0:
        return native_v
    if swapped_v >= 2.0 and native_v < 1.0:
        return swapped_v
    return swapped_v


def _read_adc_voltage(bus, address, channel_cfg, cfg, decode_mode="swapped"):
    bus.write_i2c_block_data(address, 0x01, [0x85, 0x83])
    bus.write_i2c_block_data(address, 0x00, [0x00, 0x00])
    time.sleep(cfg.channel_sleep_s)

    bus.write_i2c_block_data(address, 0x01, [channel_cfg, 0x43])
    time.sleep(cfg.channel_sleep_s)

    raw = bus.read_word_data(address, 0x00)
    return _decode_adc_voltage_from_raw(raw, cfg, decode_mode)


def _temp_c_from_tempv(temp_v, profile):
    if profile == "piz_uptime_2":
        return (4.0 - temp_v) / 0.0432
    if profile == "pi_uptime_ups_2":
        return (4.236 - temp_v) / 0.0408
    raise ValueError("Unknown temp_profile: %r" % profile)
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

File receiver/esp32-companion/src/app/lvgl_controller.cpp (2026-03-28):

#include "lvgl_controller.h"

#include <SD.h>
#include <esp_heap_caps.h>
#include <math.h>
#include <SPI.h>
#include <WiFi.h>
#include <string.h>

namespace {

constexpr uint32_t kUiRefreshIntervalMs = 120;
constexpr uint32_t kCommandStatusShowMs = 3000;
constexpr uint32_t kCommandConfirmTimeoutMs = 5000;
constexpr uint32_t kGroundStationOfflineDetectMs = 8000;
constexpr uint8_t kCalPointCount = 4;
constexpr uint8_t kTelemetryTxPowerMinDbm = 2;
constexpr uint8_t kTelemetryTxPowerMaxDbm = 17;
constexpr lv_coord_t kSettingsPanelTopOffsetPx = 40;
constexpr lv_coord_t kSettingsPanelRightInsetPx = 4;
constexpr lv_coord_t kSettingsPanelBottomMarginPx = 8;
constexpr int kCalMarginPx = 24;
constexpr int32_t kCalRetouchDistancePx = 120;
constexpr int32_t kTouchPressThreshold = 140;
constexpr int32_t kTouchReleaseThreshold = 90;
constexpr lv_coord_t kActionPanelGapPx = 10;
constexpr lv_coord_t kActionItemsGapPx = 16;
constexpr lv_coord_t kSettingsButtonHeight = 28;
constexpr lv_coord_t kSettingsStackGapPx = 12;
constexpr lv_coord_t kSettingsPanelMaxHeight = 262;
constexpr lv_coord_t kSettingsRowGapPx = 14;
constexpr lv_coord_t kTrendChartTopOffsetPx = 76;
constexpr lv_coord_t kTrendChartHeightPx = 220;
constexpr int32_t kTrendChartScaleMax = 100;
constexpr float kTrendAltMinSpanM = 20.0f;
constexpr float kTrendVsMinSpanMps = 4.0f;

static int32_t normalizeTrendValue(float value, float minValue, float maxValue) {
  if (isnan(value) || isnan(minValue) || isnan(maxValue) || maxValue <= minValue) {
    return LV_CHART_POINT_NONE;
  }

  float ratio = (value - minValue) / (maxValue - minValue);
  if (ratio < 0.0f) {
    ratio = 0.0f;
  } else if (ratio > 1.0f) {
    ratio = 1.0f;
  }

  return static_cast<int32_t>(lroundf(ratio * static_cast<float>(kTrendChartScaleMax)));
}
constexpr int32_t kUiFontSizePx = 14;

extern const uint8_t kEmbeddedSlkscrTtfStart[] asm("_binary_resources_slkscr_ttf_start");
extern const uint8_t kEmbeddedSlkscrTtfEnd[] asm("_binary_resources_slkscr_ttf_end");

static uint16_t median3(uint16_t a, uint16_t b, uint16_t c) {
  if (a > b) {
    const uint16_t t = a;
    a = b;
    b = t;
  }
  if (b > c) {
    const uint16_t t = b;
    b = c;
    c = t;
  }
  if (a > b) {
    const uint16_t t = a;
    a = b;
    b = t;
  }
  return b;
}

static int32_t mapLinearRange(int32_t value,
                              int32_t inMin,
                              int32_t inMax,
                              int32_t outMin,
                              int32_t outMax) {
  if (inMax == inMin) {
    return outMin;
  }
  const int64_t numerator = static_cast<int64_t>(value - inMin) * static_cast<int64_t>(outMax - outMin);
  const int64_t denominator = static_cast<int64_t>(inMax - inMin);
  return static_cast<int32_t>(static_cast<int64_t>(outMin) + (numerator / denominator));
}

#ifndef AUTO_TOUCH_CALIBRATION_AT_BOOT
#define AUTO_TOUCH_CALIBRATION_AT_BOOT 0
#endif

#ifndef COMPANION_BAT_ADC_PIN
#define COMPANION_BAT_ADC_PIN 34
#endif

#ifndef COMPANION_BAT_ADC_DIVIDER_SCALE
#define COMPANION_BAT_ADC_DIVIDER_SCALE 2.0f
#endif

#ifndef COMPANION_BAT_ADC_CAL_SCALE
#define COMPANION_BAT_ADC_CAL_SCALE 1.0f
#endif

#ifndef COMPANION_BAT_ADC_SAMPLES
#define COMPANION_BAT_ADC_SAMPLES 16
#endif

#ifndef COMPANION_BAT_SAMPLE_INTERVAL_MS
#define COMPANION_BAT_SAMPLE_INTERVAL_MS 1000
#endif

#ifndef COMPANION_BAT_ADC_MIN_VALID_MV
#define COMPANION_BAT_ADC_MIN_VALID_MV 50
#endif

#ifndef COMPANION_SD_ENABLE
#define COMPANION_SD_ENABLE 0
#endif

#ifndef COMPANION_SD_CS_PIN
#define COMPANION_SD_CS_PIN -1
#endif

#ifndef COMPANION_SD_SPI_FREQ
#define COMPANION_SD_SPI_FREQ 10000000
#endif

#ifndef COMPANION_SD_SCK_PIN
#define COMPANION_SD_SCK_PIN 18
#endif

#ifndef COMPANION_SD_MISO_PIN
#define COMPANION_SD_MISO_PIN 19
#endif

#ifndef COMPANION_SD_MOSI_PIN
#define COMPANION_SD_MOSI_PIN 23
#endif

#ifndef COMPANION_SD_SOUND_DIR
#define COMPANION_SD_SOUND_DIR "/sounds"
#endif

#ifndef COMPANION_AUDIO_ENABLE
#define COMPANION_AUDIO_ENABLE 0
#endif

#ifndef COMPANION_AUDIO_SPK_PIN
#define COMPANION_AUDIO_SPK_PIN -1
#endif

#ifndef COMPANION_AUDIO_PWM_CHANNEL
#define COMPANION_AUDIO_PWM_CHANNEL 0
#endif

#ifndef COMPANION_AUDIO_PWM_FREQ
#define COMPANION_AUDIO_PWM_FREQ 32000
#endif

#ifndef COMPANION_AUDIO_PWM_BITS
#define COMPANION_AUDIO_PWM_BITS 8
#endif

#ifndef COMPANION_SOUND_FILE_POWER_ON
#define COMPANION_SOUND_FILE_POWER_ON "/sounds/power_on.wav"
#endif

#ifndef COMPANION_SOUND_FILE_ARMED
#define COMPANION_SOUND_FILE_ARMED "/sounds/armed.wav"
#endif

#ifndef COMPANION_SOUND_FILE_CALIBRATING
#define COMPANION_SOUND_FILE_CALIBRATING "/sounds/calibrating.wav"
#endif
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

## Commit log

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2026-01-18 Change GNSS polling from fixed-rate timer to data-available trigger for more responsive serial stream capture
    [main.cpp]
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2026-01-18 Replace rewind() with seekSet(0), remove IRAM_ATTR from PPS ISR, rename LoRa module variable, and reduce BMP390 oversampling to none for lower latency
    [sensors.cpp]
2026-01-19 Add teensy41_debug environment, implement DEBUG_MODE macros, and add debug logging throughout initialization and error paths
    [cfg.h, main.cpp]
2026-01-19 Add comprehensive Part 97 compliance framework for LoRa telemetry with duty-cycle restraint, automatic landing shutdown, and cleartext station identification
    Implement FCC Part 97 amateur radio compliance for LoRa transmissions including mandatory callsign embedding in human-readable ASCII, deterministic scheduling with minimum TX intervals, meaningful-change thresholds for duty-cycle restraint, bounded retries with exponential backoff, hard failsafes (TX watchdog, maximum mission duration, landing
    [cfg.h, lora_link.h, main.cpp]
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2026-01-26 Adds GNSS failover and IMU sensor integration
    - Introduces dual GNSS UARTs with failover timeout and runtime selection; anchors time to healthy stream and routes data accordingly.
    - Refactors GNSS interface to use a HardwareSerial reference, enabling support for primary and backup ports and an optional ring sink.
    - Updates main loop to initialize and poll both GNSS ports with dynamic failover switching between primary and backup.
    - Integrates IMU stack (gyro and accelerometer) over I2C, initializes sensors, reads data, converts units (mg, deg/s) and temperature, and reports status.
    - Adds new IO pins and config for GNSS/IMU, and updates build dependencies for Adafruit BusIO and IMU drivers.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
    [cfg.h, main.cpp, sensors.cpp]
2026-01-26 Favor primary GNSS anchor when fresh
    Switches the GNSS time anchor logic to prioritize the primary receiver when its data is fresh, using the backup only as a fallback. This improves reliability by reducing unnecessary reliance on the backup source and aligns failover behavior with the intended primary role.
    [main.cpp]
2026-01-26 Implements GNSS UBX-based configuration and baud-rate update
    Replaces the GNSS configuration stub with a full UBX-based init sequence:
    - Adds UBX message building and checksum helpers and a small send wrapper
    - Configures GNSS port (port 1) with chosen baud and protocol masks
    - Enables a range of UBX/NMEA messages via CFG-MSG
    - Sets GNSS measurement rate (CFG-RATE) based on GNSS_HZ
    - Guards against zero GNSS_HZ to skip rate setup
    - Uses GNSS_BAUD for UART configuration and updates references in docs
    Also updates baud rate in configuration and README to 115200 to reflect the change
    [cfg.h]
2026-01-26 Add readiness checks to IMU read
    Introduce readiness gating for IMU reads to keep the path non-blocking when sensors aren't ready. The code now checks LRDY_PIN and GRDY_PIN (with 255 treated as always-ready), avoids blocking when neither sensor is ready, and only reads accelerometer and/or gyroscope when their respective sensors are reported ready. This reduces latency and prevents unnecessary blocking in the IMU path.
    [sensors.cpp]
2026-01-26 Improves sensor polling cadence and cleans up unused vars
    Refactors IMU and Barometer scheduling to be drift-tolerant:
    - compute fixed polling periods from configured Hz
    - initialize timestamps on first run
    - process backlog with a bounded loop (up to 4 IMU iterations, 2 Baro iterations) to catch up without starving other tasks
    - write samples using their respective reference timestamps
    Removes unused state variables (GNSS timer and error counter) and updates Adafruit L3GD20 library reference to the supported name
    [main.cpp]
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2026-01-26 Adds UBX NAV-PVT parsing and enhanced debug output
    Introduces a lightweight UBX NAV-PVT parser to extract GNSS time/position data and exposes useful diagnostics for debugging. Adds little-endian helpers and a per-byte UBX state machine, integrates parsing into the GNSS receive loop, and stores/exposes new time fields (fix type, lat/lon, height) plus last PVT timestamp. Tracks bytes received from GNSS and makes them available for diagnostics.
    Also expands debug capabilities:
    - Waits for serial readiness during DEBUG builds to ensure logs appear reliably.
    - Augments periodic debug output with barometer, temperature, ring status, IMU data (when available), GNSS status, and SD logging errs.
    Ad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
    [cfg.h, main.cpp]
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2026-01-26 Improve sensor init flow and BMP SPI support
    - Disable unused READY indicators by setting GRDY_PIN and LRDY_PIN to 255.
    - Add explicit BMP SPI pins and switch BMP interface from I2C/SPI mix to SPI1; reduce I2C speed to 400 kHz.
    - Introduce BMP3XX SPI initialization sequence with proper CS/MOSI/SCK/MISO setup; fail early if BMP SPI init fails.
    - Separate sensor readiness state for gyro and accel; adjust read path to proceed if at least one is available.
    - Add debug-friendly I2C bus scan in SENSOR init (within DEBUG_MODE) to enumerate connected devices and aid troubleshooting.
    - Improve initialization diagnostics: log results of sensor boot (gyro/accel) and BMP status; report sensor init outco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
    [cfg.h, main.cpp, sensors.cpp]
2026-01-26 Implements non-blocking buzzer state machine
    Introduces a non-blocking buzzer control system with a small state machine and a periodic poll, replacing direct PIN toggling with a buzzer wrapper and enabling sequenced beeps without blocking main execution.
    Key changes:
    - Adds a buzzer state machine (active, on/off timing, next trigger) plus a non-blocking poll function.
    - Replaces immediate digital writes with a safe buzzer_set wrapper for pin control.
    - Provides standard beeps for startup (boot ok) and for subsystem statuses (SD logger, GNSS, sensors).
    - Signals a one-time startup sequence on boot and a special 2-beep sequence when the primary GNSS achieves a 3D fix.
    - Uses a polling approac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
    [main.cpp]
2026-01-26 Adds success/failure feedback for LoRa init
    Uses the boolean result of the initialization call to emit a success buzzer when initialization succeeds and a failure buzzer when it fails, instead of always signaling success. This improves startup diagnostics and makes LoRa initialization outcomes explicit. The change is scoped inside the existing ENABLE_LORA block.
    [main.cpp]
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2026-01-28 Adds graceful shutdown with resource cleanup to Pi LoRa receiver
    Wraps the main loop in try/except/finally to handle KeyboardInterrupt and ensure proper cleanup on exit. Adds SPI.close() method to close the spidev connection. Cleanup sequence turns off LED, deasserts chip select, closes SPI bus, and calls GPIO.cleanup(). All cleanup steps are wrapped in individual try/except blocks to prevent cascading failures during shutdown.
    [lora_receive_pi.py]
2026-01-29 Adds LoRa sync word/preamble config and expands GNSS debug output
    Configures LoRa sync word (0x34) and preamble length (8) to match receiver scripts. Adds debug prints for LoRa TX start/done with timing and payload. Expands GNSS debug output to show both primary and backup receiver status (freshness, fix, position, byte counts) plus selected receiver indicator, improving dual-GNSS diagnostics.
    [main.cpp]
2026-01-29 Changes Pi LoRa receiver to use hardware CS with updated pin mappings
    Switches from software chip select (GPIO 17) to hardware SPI CS0 (GPIO 8) by setting `no_cs = False` and adding `USE_HW_CS` flag. Updates pin assignments to match new wiring: NSS/CS to GPIO 8, RST to GPIO 25, DIO0 to GPIO 22. Conditionally initializes NSS pin and skips manual CS toggling when hardware CS is enabled.
    [lora_receive_pi.py]
2026-01-29 Replaces ASCII telemetry with binary protocol and splits ID/data transmissions
    Switches LoRa telemetry from verbose ASCII format to compact binary protocol (0xA1 header). Separates station identification (type 1) from sensor data (type 0) into independent transmit cycles with separate retry logic. ID packets now transmit on heartbeat interval with callsign only, while data packets send timestamp/pressure/temperature in 12 bytes. Removes ring buffer drops, spool drops, and SD error counts from telemetry payload
    [lora_link.h, lora_receive_pi.py, lora_receive_pico.py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]
2026-01-29 Conditionally configures NSS pin mode based on hardware CS flag
    Changes NSS pin initialization to skip OUT mode when hardware chip select is enabled, preventing GPIO conflicts with SPI0 CS0 control.
    [lora_receive_pi.py]
2026-01-29 Replaces split write/read operations with atomic xfer transactions in SPI methods
    Adds SPI.xfer() method wrapping spidev.xfer2() and refactors all register/FIFO access to use single atomic transactions instead of separate write/read calls. Conditionally skips manual CS toggling when hardware CS is enabled. Improves SPI timing reliability by eliminating gaps between address write and data read phases.
    [lora_receive_pi.py]
2026-01-29 Adds hardware CS fallback with version check and configurable SPI baudrate
    Introduces `init_radio()` helper to encapsulate SPI/radio initialization with configurable chip select mode. Adds `no_cs` parameter to SPI class constructor to control kernel-driven CS. Implements automatic fallback from hardware CS (GPIO 8) to software CS on same pin if RegVersion register read fails validation (expected 0x12). Adds `SPI_BAUDRATE` constant (100 kHz) and version register debug output showing raw transaction
    [lora_receive_pi.py]
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2026-01-29 Adds GPS and IMU telemetry transmission with interval-based scheduling
    Extends LoraLink to transmit GPS (type 2) and IMU (type 3) packets alongside altimeter data (type 0). Replaces change-detection logic with interval-based scheduling using LORA_GPS_INTERVAL_MS, LORA_ALT_INTERVAL_MS, and LORA_IMU_INTERVAL_MS. Implements priority selection that picks the most overdue packet type when multiple are ready. Adds start_gps_tx() and start_imu_tx() methods to encode 18-byte packets with timestamp plus
    [lora_link.h, main.cpp]
2026-01-29 Adds conditional compilation guards for buzzer functionality using ENABLE_BUZZER flag
    Wraps all buzzer-related code in `#if ENABLE_BUZZER` preprocessor directives to allow disabling buzzer at compile time. Adds `(void)parameter` casts in disabled code paths to suppress unused variable warnings. Affects buzzer_set(), buzzer_start_seq(), buzzer_poll(), buzzer_pulse(), and setup() initialization.
    [main.cpp]
2026-01-29 Removes GPS fix check from LoRa transmission and simplifies packet priority selection
    Removes `gps->fix_ok` condition from GPS transmission eligibility check, allowing GPS packets to transmit regardless of fix status. Replaces priority selection logic that picked most overdue packet with simple if/else chain prioritizing GPS > altimeter > IMU. Removes unused `best_late` variable. Also removes `Serial.available()` guards from GNSS polling, allowing poll() to run unconditionally.
    [main.cpp]
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2026-01-29 Adds offline map tile caching system with download manager and setup interface
    Implements MapDownloadManager class that downloads OpenStreetMap tiles for specified geographic bounds and zoom levels. Manager calculates tile coordinates from lat/lon bounds, validates requests against MAX_TILE_REQUEST limit (50k tiles), downloads tiles via urllib with configurable timeout/user-agent, and maintains thread-safe download state (progress/errors/cancellation). Adds /tiles/{z}/{x}/{y}.png endpoint to serve cached tiles and
    [ground_station_server.py, lora_receive_pi.py, main.cpp]
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2026-01-30 Swaps IMU axis mapping to correct sensor orientation (x↔y for accel/gyro, y↔z for accel)
    [sensors.cpp]
2026-02-01 Removes raw telemetry fields from web UI and enables LoRa TX with callsign configuration
    Removes raw/debug telemetry fields from ground station web interface: radio ASCII/HEX payloads, GPS e7/mm values, altimeter x10/x100 raw values, IMU raw counts, and battery mV. Replaces raw payload fields with "Last Packet" timestamp using new formatTimestamp() helper that converts Unix epoch to locale string. Sets LORA_CALLSIGN to "KG5CKI" and enables LORA_TX_ENABLE_AT_BOOT (0→1) for automatic transmission
    [cfg.h]
2026-02-07 Adds NAV-SAT telemetry with satellite count and C/N0 metrics to ground station
    Implements new NAVSAT payload type (ID 5) that transmits GPS satellite statistics: total SVs visible, SVs used in solution, max C/N0, and average C/N0. Adds NAVSAT telemetry block to web UI displaying satellite counts and signal strength metrics. Implements map controls with "Jump to current" button (re-enables auto-follow and pans to last GPS fix) and "Set home" button (clears GPS track, sets home marker at next fix with
    [ground_station_server.py, lora_link.h, lora_receive_pi.py]
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2026-02-07 Fixes SD log dump CRC calculation and removes redundant min template parameters
    Updates sd_dump_skip_bytes() to accumulate CRC32 during skip operations by adding optional crc parameter and updating CRC for each read chunk. Removes explicit template parameters from min() calls throughout main.cpp (min<uint16_t> → min, min<uint32_t> → min) and casts second argument instead. Removes const qualifier from SdLogger::open_log_read() declaration and definition to allow non-const file operations.
    [main.cpp]
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2026-02-07 Adds IMU data-ready pin configuration and SD log clear command
    Implements configurable DRDY pin polarity and pull-up settings for gyro/accel (GYRO_RDY_ACTIVE_LOW, GYRO_RDY_PULLUP, ACCEL_RDY_ACTIVE_LOW, ACCEL_RDY_PULLUP). Updates sensors.cpp to use imu_ready_pin_mode() and imu_ready_level() helpers for proper pin initialization and level detection. Enables GRDY_PIN (34) and LRDY_PIN (37) in cfg.h. Adds 'c' command to clear all LOG*.BIN files from SD card and start new log with reset block sequence
    [cfg.h, main.cpp, sensors.cpp]
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2026-02-08 Changes command ACK retry behavior to use fixed repeat interval and preserves SD logging state during clear operation
    Updates LoraLink to use LORA_ACK_REPEAT_COUNT (3) and LORA_ACK_REPEAT_MS (400ms) constants instead of exponential backoff for command acknowledgment retries. Removes enter_silence_() call from schedule_ack_retry_() and simplifies retry logic to use fixed interval. Adds debug logging for received LoRa commands. Modifies sd_clear_logs() to preserve logging state - only restarts logging if
    [main.cpp]
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2026-02-08 Adds telemetry waiting indicator and enables LoRa TX on command receipt with buzzer feedback
    Implements "Waiting for the start signal" message in ground station UI that displays when packet_count is 0 and SD logging is disabled. Hides indicator when telemetry arrives or SD logging starts. Adds buzzer beep (60ms, 1 count) on LoRa command receipt in main.cpp. Enables LoRa transmitter based on sd_logging_enabled state before queueing command acknowledgment.
    [main.cpp]
2026-02-08 Adds remote buzzer control via LoRa commands with configurable duration
    Implements LORA_CMD_BUZZER (0x03) command type with duration argument (1, 5, 10, or 30 seconds). Updates ground station server with buzzer command support in send_lora_command() including duration validation. Adds buzzer control panel to web UI with duration dropdown selector and activate button with pending/success/error status display. Updates LoraLink::pop_command() to accept optional arg parameter for command arguments an
    [ground_station_server.py, lora_link.h, lora_receive_pi.py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]
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2026-02-16 Adds OLED status display integration to ground station with real-time telemetry monitoring
    Implements OledStatusDisplay class using adafruit-ssd1306 library to show rocket telemetry on 128x32 I2C OLED (0x3C address). Displays 4-line status: callsign/packet count/RSSI, rocket battery voltage/state, Pi battery/input voltage, and altitude/flight phase or voltage monitor warnings. Updates at 500ms intervals with thread-safe locking. Gracefully disables on non-Linux platforms or missing dependencies.
    [ground_station_server.py]
2026-02-16 Adds TrueType font support to OLED display using Pillow for improved text rendering
    Replaces adafruit-ssd1306's built-in text() method with PIL ImageDraw for custom font rendering. Loads slkscr.ttf (8pt) from resources directory with fallback to default font if unavailable. Switches from direct display.text() calls to rendering on PIL Image then transferring to display. Adds Pillow to requirements.txt and implements font loading with error handling in _load_font(). Stores display dimensions and font instance
    [ground_station_server.py]
2026-02-16 fix: critical ground station reliability and security fixes
    - Add LoRa SPI retry loop with exponential backoff (1s-30s, max 10 retries)
    - Bind Flask to localhost by default, add GS_AUTH_TOKEN for command endpoints
    - Fix SSE client leak on disconnect (broad exception catch)
    [ground_station_server.py]
2026-02-16 fix: exempt map download/cancel endpoints from auth check
    Map tile operations are local convenience features, not rocket commands.
    Auth still required for /api/command, attitude filter/threshold endpoints.
    [ground_station_server.py]
2026-02-16 Add configurable voltage divider constants for battery monitoring with 220k/100k resistor values
    Replaces hardcoded 2.0x scaling factor with calculated VBAT_DIVIDER_SCALE based on explicit resistor values (220kΩ top, 100kΩ bottom). Adds documentation noting 2S LiPo full charge (8.4V) produces safe 2.625V at ADC pin. Maintains VBAT_CAL_SCALE for fine-tuning.
    [cfg.h, main.cpp]
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2026-02-17 feat(companion): add touchscreen command controls (phase 3)
    - Add XPT2046 touch support + config pins/calibration
    - Add on-screen buttons for buzzer 1s/5s and SD logging toggle
    - Add authenticated /api/companion/cmd client call
    - Update companion README for touch setup
    [controller.cpp]
2026-02-17 feat(companion): add phase 4 UX hardening (alerts, command feedback, touch calibration mode)
    - Parse and surface companion alerts on-device
    - Add alert strip and recent event notifications
    - Add command send success/fail feedback in footer
    - Add quick touch calibration view (enter top-left, exit top-right)
    [controller.cpp, telemetry_state.h]
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2026-02-17 feat(teensy): wire companion UART skeleton into main loop
    - Init companion UART serial in setup
    - Send telemetry snapshot to ESP32 at 10 Hz
    - Receive ESP32 commands (sd_start/sd_stop/buzzer)
    - Execute commands and send command acks
    - Add companion UART config toggles in cfg.h
    [cfg.h, main.cpp]
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2026-02-17 fix(companion-uart): move serial bridge to Pi ground station and drop Teensy path
    - Add optional Pi<->ESP32 UART bridge in ground_station_server.py
    - Stream companion telemetry frames over UART and handle incoming cmd frames
    - Add env-configurable UART port/baud toggles (GS_COMPANION_UART*)
    - Add pyserial dependency
    - Remove Teensy UART helper files and revert Teensy integration changes
    - Align UART protocol docs to Pi-ground-station topology
    [ground_station_server.py]
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2026-02-17 fix(display): apply LCDWiki E32R32P pin map and force backlight on
    - Configure TFT_eSPI via build flags for ST7789 + board SPI pins
    - Set default UART header pins to RXD0(IO3)/TXD0(IO1)
    - Force LCD backlight pin IO27 high in setup
    - Update README/UART docs with board pin mapping notes
    - Verified local PlatformIO build succeeds
    [main.cpp]
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2026-02-18 fix(uart0): prevent USB serial debug from corrupting UART companion link on IO1/IO3
    [main.cpp, uart_link.cpp]
2026-02-18 docs(uart): update references from Teensy to Pi ground station
    - Replace Teensy references with Pi in test checklist and config docs
    - Add clarification that UART bridge connects Pi <-> ESP32
    - Add startup log message when UART bridge is disabled
    - Document LCDWiki board UART0 pin mapping in protocol docs
    [ground_station_server.py]
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2026-02-19 feat(esp32): optimize display rendering with partial updates and move UART pins to avoid USB conflict
    - Change UART pins from IO1/IO3 to IO32/IO25 to prevent USB serial corruption
    - Implement dirty-line tracking in tty_echo for incremental screen updates
    - Split MainScreen::render() into modular draw functions (header/primary/alert/footer/buttons)
    - Reduce MainScreen render throttle from 250ms to 100ms for smoother updates
    - Add bodyNeedsFullRedraw flag to minimize full-screen redraws in UART echo
    [tty_echo_main.cpp]
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2026-02-20 feat(esp32): conditionally compile companion battery monitoring based on UART link mode
    - Guard updateCompanionBattery() with COMPANION_LINK_UART check to skip ADC reads in WiFi mode
    - Conditionally configure BAT_ADC_PIN as INPUT only when UART link is enabled
    - Prevents unnecessary battery monitoring overhead when using WiFi API client
    [controller.cpp]
2026-02-21 docs(esp32): update README for LVGL-based CrowPanel 3.5 companion display
    - Replace Phase 2 scaffold docs with LVGL migration notes
    - Update hardware target to CrowPanel 3.5" ESP32 HMI (480x320 landscape)
    - Document new LVGL UI features: collapsible action/settings panels, NVS touch calibration
    - Add CrowPanel pin configuration notes (ILI9488 + XPT2046, TFT_MISO/TOUCH_CS variants)
    - Update config.h.example defaults: COMPANION_LINK_UART=1, UART pins 3/1, bootstrap touch calibration values
    - Update
    [ground_station_server.py, lvgl_controller.cpp, lvgl_controller.h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]
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2026-02-21 feat(esp32): migrate touch controller from XPT2046_Touchscreen to TFT_eSPI native touch with debug overlay
    - Replace XPT2046_Touchscreen library with TFT_eSPI's built-in touch support (getTouchRaw/getTouchRawZ)
    - Add local TFT_eSPI library dependency to enable custom touch configuration
    - Implement readTouchRaw() helper with Z-threshold filtering (600) for reliable touch detection
    - Add comprehensive touch debug overlay showing raw/mapped coordinates, Z-pressure, IRQ state, and sample age
    - Revert
    [controller.cpp, lvgl_controller.cpp, lvgl_controller.h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]
2026-02-21 feat(esp32): hide touch debug overlay and fix type warning in touch mapping
    - Hide touchDebugLabel_ by default with LV_OBJ_FLAG_HIDDEN flag
    - Add explicit int cast to sy in mapTouchToScreen() to match outY type
    - Remove touch debug label updates from refreshUi() (no longer displayed)
    [lvgl_controller.cpp]
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2026-02-22 feat(esp32): add interactive touch calibration with median filtering and toggle-based action UI
    - Replace XPT2046_Touchscreen with TFT_eSPI native touch using 3-sample median filtering for stability
    - Add hysteresis-based touch detection (press: 140, release: 90) to prevent bouncing
    - Implement automatic retouch detection (120px threshold) during calibration for accuracy
    - Replace action panel toggle with compact icon-based menu bar (SD/TX toggles + action/settings buttons)
    - Add interactive buz
    [ground_station_server.py, lvgl_controller.cpp, lvgl_controller.h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]
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2026-02-22 feat(esp32): migrate LVGL display and input drivers to v9 API
    - Replace deprecated lv_disp_drv_t/lv_disp_draw_buf_t with lv_display_t and lv_display_create()
    - Replace deprecated lv_indev_drv_t registration with lv_indev_create() and setter functions
    - Change draw buffer from lv_color_t* to uint8_t* with explicit RGB565 format
    - Update flush callback signature from lv_color_t* to uint8_t* pixel map
    - Add null checks in callbacks for safer user_data access
    - Use lv_display_set_buffers() with LV_DISPLAY_RENDER_
    [lvgl_controller.cpp, lvgl_controller.h]
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
